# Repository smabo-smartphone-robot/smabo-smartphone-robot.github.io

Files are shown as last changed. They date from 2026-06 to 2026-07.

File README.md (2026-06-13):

# smabo-smartphone-robot.github.io

smabo プロジェクトの公式サイト（GitHub Pages）。

公開URL: <https://smabo-smartphone-robot.github.io/>

ビルド不要の静的サイト（プレーンな HTML / CSS / JS、外部ライブラリ依存なし）です。

## ファイル構成

```
.
├── index.html            # トップページ（特徴・システム構成・できること・リポジトリ）
├── components.html       # コンポーネント詳細（app / esp32 / brain）
├── roadmap.html          # ロードマップ
├── css/
│   ├── style.css         # サイト共通スタイル
│   ├── roadmap.css       # ロードマップ用
│   └── docs.css          # ドキュメント本文用（Markdown→HTML 表示）
├── js/
│   ├── main.js           # ナビ開閉・フッター年号
│   ├── roadmap.js        # ロードマップ用
│   └── docs.js           # ドキュメント用（Mermaid 描画・TOCスクロール追従）
├── assets/
│   ├── favicon.svg       # ファビコン
│   └── robot.svg         # ヒーローのロボットイラスト
├── docs/                 # ドキュメント（Markdown 正本 ＋ 生成 HTML を併置）
│   ├── index.md / index.html       # ドキュメントのトップ
│   ├── architecture/
│   │   └── design.md / design.html # 設計書（ESP32 ファームウェア設計）
│   ├── guides/                     # 製作ガイド（*.html）
│   └── images/                     # 図・スクショ
└── .nojekyll             # Jekyll 処理を無効化
```

## ドキュメント（Markdown ↔ HTML）

`docs/` 配下は **Markdown 版（正本）と HTML 版（公開用）を同じ場所・同じ名前で併置**します
（例: `architecture/design.md` ↔ `architecture/design.html`）。

- **Markdown** が編集の正本。記事を書く／直すときは `.md` を編集します。
- **HTML** は `.md` を元に生成します（サイト共通の `css/style.css` ＋ `css/docs.css` を適用、
  本文は `<article class="doc-content">` に流し込み、見出しからサイドバー目次を生成）。
- ` ```mermaid ` ブロックは `<pre class="mermaid">` として出力し、`js/docs.js` が
  Mermaid を CDN から読み込んで描画します（図を含むページのみ読み込み）。
- 変換はビルド工程を持たず、`.md` の内容を元に都度 HTML を作成します。`.md` を更新したら
  対応する `.html` を作り直してください。

## ローカルでの確認

```bash
# リポジトリ直下で簡易サーバを起動
python3 -m http.server 8000
# ブラウザで http://localhost:8000 を開く
```

## 公開（デプロイ）

`main` ブランチへ push すると GitHub Pages が自動で公開します
（Settings → Pages で Source を `main` / `/ (root)` に設定）。

## 編集メモ

- ヘッダーとフッターは各 HTML に直接記述しています（テンプレートエンジンなし）。
  ナビ項目を変更する場合は `index.html` と `components.html` の両方を更新してください。
- コンテンツは各リポジトリの README をもとにしています。仕様を変えたら本サイトも追従させてください。

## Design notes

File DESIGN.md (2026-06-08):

# ESP32 Robot Firmware — 設計ドキュメント

- **対象ファームウェア**: MicroPython (ESP32)
- **通信プロトコル**: rosbridge v2.0 互換 WebSocket JSON
- **更新日**: 2026-06-03

---

## 目次

1. [モジュール構成](#1-モジュール構成)
2. [クラス図](#2-クラス図)
3. [非同期タスク構成](#3-非同期タスク構成)
4. [シーケンス図](#4-シーケンス図)
   - 4-1. 起動
   - 4-2. WebSocket 接続確立
   - 4-3. 走行制御 (cmd_vel)
   - 4-4. サーボ手動制御（単一点）
   - 4-5. サーボ軌道制御（複数点・MoveIt2）
   - 4-6. ナビゲーション連携（Nav2）
   - 4-7. ランダム動作
   - 4-8. ソフト設定変更
   - 4-9. ハード設定変更（ピン変更・再起動）
   - 4-10. モード切り替え
   - 4-11. /joint_states 送信ループ
   - 4-12. オドメトリ送信ループ
   - 4-13. 設定の読み出し
5. [WebSocket メッセージ仕様](#5-websocket-メッセージ仕様)
6. [設定項目一覧](#6-設定項目一覧)
7. [設定変更の反映ルール](#7-設定変更の反映ルール)
8. [ハードウェア構成メモ](#8-ハードウェア構成メモ)

---

## 1. モジュール構成

```
esp32_robot/
├── main.py              # 起動エントリ・asyncio イベントループ
├── config.py            # 永続設定（RAM + config.json、デバウンス保存）
├── wifi_manager.py      # WiFi 接続・自動再接続
├── ws_server.py         # RFC 6455 WebSocket サーバ（外部ライブラリ不要）
├── robot.py             # オーケストレータ（rosbridge プロトコル・モード管理）
├── pca9685.py           # PCA9685 PWM ドライバ（サーボ用 I2C）
├── servo_controller.py  # JointGroup（全サーボ共通）
├── random_motion.py     # グループ単位のランダム動作（タイミンググループ管理）
├── dc_motors.py         # TB6612 差動駆動（cmd_vel 受信・デッドマン停止）
├── encoder.py           # GPIO 割り込みによるエンコーダカウント
└── odometry.py          # 差動駆動オドメトリ → nav_msgs/Odometry
```

---

## 2. クラス図

```mermaid
classDiagram
    direction TB

    class Config {
        +data : dict
        +get(path, default) any
        +set(path, value, persist)
        +update(partial, persist)
        +save_now()
        +mark_dirty(debounce_ms)
        +autosave_task() async
    }

    class WSServer {
        +port : int
        +clients : set
        +on_message : callable
        +start() async
        +broadcast(text)
        -_handshake(reader, writer) async
        -_read_loop(reader, writer) async
    }

    class Robot {
        +cfg : Config
        +pca : PCA9685
        +ws  : WSServer
        +servo_group   : JointGroup
        +random_motion : RandomMotion
        +drive    : DiffDrive
        +encoders : tuple
        +odom     : Odometry
        +start()
        +on_message(client, text)
        +apply_modes(modes)
        +publish(topic, msg)
        -_on_set_config(config_dict)
        -_reload_subsystems(changed_keys)
        -_joint_states_task() async
        -_reboot_after(ms, reasons) async
    }

    class PCA9685 {
        +i2c  : I2C
        +addr : int
        +set_freq(freq)
        +set_us(channel, us)
        +off(channel)
    }

    class JointGroup {
        +pca         : PCA9685
        +joints      : dict
        -_traj_queue : list
        +set_angle_deg(name, angle)
        +load_trajectory(names, points)
        +get_state() dict
        +run(dt) async
    }

    class RandomMotion {
        +group : JointGroup
        +cfg   : Config
        +run_group(group_name) async
        -_behavior() str
        -_group_cfg(name) dict
    }

    class DiffDrive {
        +cfg   : Config
        +left  : _Motor
        +right : _Motor
        +stby  : Pin
        +set_cmd_vel(linear_x, angular_z)
        +stop()
        +watchdog_task() async
    }

    class _Motor {
        +pwm  : PWM
        +in1  : Pin
        +in2  : Pin
        +drive(value)
        +stop()
    }

    class QuadEncoder {
        -_count : int
        +read() int
        +read_and_reset() int
    }

    class Odometry {
        +x     : float
        +y     : float
        +theta : float
        +vx    : float
        +wz    : float
        +update()
        +odom_msg() dict
        +run(publish) async
    }

    Robot --> Config         : 参照
    Robot --> WSServer       : 参照
    Robot --> PCA9685        : 参照
    Robot "1" *-- "0..1" JointGroup   : servo_group
    Robot "1" *-- "0..1" RandomMotion
    Robot "1" *-- "0..1" DiffDrive
    Robot "1" *-- "0..1" Odometry
    JointGroup   --> PCA9685    : PWM 出力
    RandomMotion --> JointGroup : 角度指令
    RandomMotion --> Config     : 参照（毎ループ読み直し）
    DiffDrive "1" *-- "2" _Motor : left / right
    Odometry --> QuadEncoder    : カウント読み取り
    Odometry --> Config         : 参照
    DiffDrive --> Config        : 参照
```

> **共通化ポイント**: 首・ハンド・アームを含む全サーボを `servo_group`（`JointGroup` の単一インスタンス）で管理します。
> ランダム動作のグループ分けは `RandomMotion` が担い、`JointGroup` 自体はグループを意識しません。

---

## 3. 非同期タスク構成

起動後に asyncio 上で動作するタスクの一覧です。
`Robot._tasks` で名前管理され、モード変更時に個別にキャンセル・再生成されます。

| タスク名 | コルーチン | 役割 | 起動条件 |
|---|---|---|---|
| `servo_follower` | `JointGroup.run()` | サーボ角度の速度制限追従・軌道キュー処理 | `modes.servos = true` |
| `random_<name>` | `RandomMotion.run_group(name)` | グループ単位のランダムタイマー（グループ数分起動） | `modes.servos = true` |
| `joint_states` | `Robot._joint_states_task()` | `/joint_states` 送信（MoveIt2連携用） | `modes.servos = true` |
| `drive_wd` | `DiffDrive.watchdog_task()` | cmd_vel デッドマン監視 | `dc_drive` or `encoder_drive` |
| `odom` | `Odometry.run()` | オドメトリ計算 + `/odom` 送信 | `modes.encoder_drive = true` |
| `autosave` | `Config.autosave_task()` | 設定デバウンス保存 | 常時 |
| `wifi_ka` | `wifi_manager.keepalive_task()` | WiFi 再接続監視 | 常時 |

> `random_<name>` のタスク名はグループ名から自動生成されます（例: `random_neck`, `random_hands`）。
> グループ数を変更すると `servos` モードが再起動され、新しいグループ数に合わせてタスクが再生成されます。

---

## 4. シーケンス図

### 4-1. 起動シーケンス

```mermaid
sequenceDiagram
    participant main
    participant Config
    participant WiFi as wifi_manager
    participant I2C/PCA as PCA9685
    participant WSServer
    participant Robot

    main->>Config: Config()
    Config->>Config: _load() — config.json を読み DEFAULTS とマージ
    main->>WiFi: connect(cfg)
    WiFi-->>main: WLAN オブジェクト

    main->>I2C/PCA: I2C() + PCA9685()
    main->>WSServer: WSServer(port, on_message)
    main->>Robot: Robot(cfg, pca, i2c, ws)
    main->>WSServer: ws.start()  ← TCP ソケットをオープン

    main->>Robot: robot.start()
    Robot->>Robot: apply_modes(cfg.modes)
    Robot->>Robot: enable_servos / enable_drive

    main->>main: asyncio tasks: autosave, wifi_keepalive
    Note over main: イベントループ開始 (sleep forever)
```

---

### 4-2. WebSocket 接続確立

```mermaid
sequenceDiagram
    participant Client as Web クライアント
    participant WSServer

    Client->>WSServer: TCP connect → HTTP GET (Upgrade: websocket)
    WSServer->>WSServer: SHA-1(key + GUID) → Sec-WebSocket-Accept
    WSServer-->>Client: HTTP 101 Switching Protocols
    Note over Client,WSServer: 以降 RFC 6455 フレームで双方向通信
    WSServer->>WSServer: clients.add(writer)
```

---

### 4-3. 走行制御 (cmd_vel)

```mermaid
sequenceDiagram
    participant Client
    participant WSServer
    participant Robot
    participant DiffDrive

    Client->>WSServer: {"op":"publish","topic":"/cmd_vel",\n"msg":{"linear":{"x":0.2},"angular":{"z":0.3}}}
    WSServer->>Robot: on_message(client, text)
    Robot->>Robot: _on_publish("/cmd_vel", msg)
    Robot->>DiffDrive: set_cmd_vel(0.2, 0.3)
    DiffDrive->>DiffDrive: 差動運動学 → v_l / v_r 正規化
    DiffDrive->>DiffDrive: left.drive(v_l),  right.drive(v_r)
    Note over DiffDrive: _last_cmd_ms を更新

    loop 100 ms ごと (watchdog_task)
        DiffDrive->>DiffDrive: ticks_diff > cmd_timeout?
        alt タイムアウト
            DiffDrive->>DiffDrive: stop()
        end
    end
```

---

### 4-4. サーボ手動制御 — 単一点 (JointTrajectory 1 点)

```mermaid
sequenceDiagram
    participant Client
    participant WSServer
    participant Robot
    participant JointGroup as servo_group

    Client->>WSServer: {"op":"publish","topic":"/servo/command",\n"msg":{"joint_names":["head_pan","head_tilt"],\n"points":[{"positions":[0.5,-0.2],"time_from_start":{"sec":0}}]}}
    WSServer->>Robot: on_message()
    Robot->>Robot: _on_publish("/servo/command", msg)
    Robot->>JointGroup: load_trajectory(names, points)
    JointGroup->>JointGroup: deadline = ticks_ms() + 0ms
    JointGroup->>JointGroup: _traj_queue = [(deadline, {head_pan:28.6°, head_tilt:-11.5°})]

    loop 20 ms ごと (servo_follower タスク)
        JointGroup->>JointGroup: deadline 到達 → _target 更新
        JointGroup->>JointGroup: max_speed 制限で _current を _target に近づける
        JointGroup->>PCA9685: set_us(channel, us)
    end
```

---

### 4-5. サーボ軌道制御 — 複数点 (MoveIt2 / time-parameterised)

```mermaid
sequenceDiagram
    participant SBC as SBC (MoveIt2)
    participant WSServer
    participant Robot
    participant JointGroup as servo_group

    SBC->>WSServer: {"op":"publish","topic":"/servo/command",\n"msg":{"joint_names":["arm_joint_1","arm_joint_2"],\n"points":[\n  {"positions":[0.0,0.0],"time_from_start":{"sec":0}},\n  {"positions":[0.5,0.3],"time_from_start":{"sec":1}},\n  {"positions":[1.0,0.6],"time_from_start":{"sec":2}}\n]}}
    WSServer->>Robot: on_message()
    Robot->>Robot: _on_publish("/servo/command", msg)
    Note over Robot: points が複数 → load_trajectory（時系列）
    Robot->>JointGroup: load_trajectory(names, points)
    JointGroup->>JointGroup: start_ms = ticks_ms()
    JointGroup->>JointGroup: _traj_queue = [(0ms,…),(1000ms,…),(2000ms,…)]

    loop 20 ms ごと (servo_follower タスク)
        JointGroup->>JointGroup: ticks_diff(now, deadline) >= 0 ?
        alt 次のポイントの時刻に到達
            JointGroup->>JointGroup: _target を該当ポイントの角度に更新
        end
        JointGroup->>JointGroup: max_speed 制限で _current を _target に追従
        JointGroup->>PCA9685: set_us(channel, us)
    end
```

> `time_from_start` は `load_trajectory()` 呼び出し時刻からの相対時間です。
> 各ポイントへの移動は `max_speed` (deg/s) の上限内でなめらかに追従します。

---

### 4-6. ナビゲーション連携（Nav2 + cmd_vel / odom）

```mermaid
sequenceDiagram
    participant PC
    participant SBC as SBC (ROS2 Nav2 + rosbridge)
    participant ESP32

    PC->>SBC: 目標位置 (geometry_msgs/PoseStamped)
    Note over SBC: Nav2 がパス計画・速度計算

    loop Nav2 制御ループ
        ESP32->>SBC: {"op":"publish","topic":"/odom","msg":{nav_msgs/Odometry}}
        Note over SBC: /odom を受信して自己位置を更新
        SBC->>ESP32: {"op":"publish","topic":"/cmd_vel","msg":{geometry_msgs/Twist}}
        Note over ESP32: DiffDrive.set_cmd_vel() → モータ制御
    end

    Note over SBC,ESP32: covariance が適切に設定されているため\nNav2 がオドメトリの信頼度を正しく評価できる
```

---

### 4-7. ランダム動作（グループ独立タイマー）

```mermaid
sequenceDiagram
    participant Client
    participant WSServer
    participant Robot
    participant RM as RandomMotion
    participant JG as servo_group (JointGroup)

    Client->>WSServer: {"op":"set_config","config":{"servos":{"behavior":"random"}}}
    WSServer->>Robot: on_message()
    Note over Robot: behavior は次のループで即時反映（再起動不要）

    par neck グループ (independent timer)
        loop random interval [1.0, 3.0] s
            RM->>RM: cfg から neck グループ設定を読む
            RM->>JG: set_angle_deg("head_pan",  random angle)
            RM->>JG: set_angle_deg("head_tilt", random angle)
            RM->>RM: sleep( random(1.0, 3.0) )
        end
    and hands グループ (independent timer)
        loop random interval [2.0, 5.0] s
            RM->>RM: cfg から hands グループ設定を読む
            RM->>JG: set_angle_deg("left_hand",  random angle)
            RM->>JG: set_angle_deg("right_hand", random angle)
            RM->>RM: sleep( random(2.0, 5.0) )
        end
    end
```

> グループ内のサーボは**同じ瞬間**に動き出しますが、目標角度はそれぞれ独立したランダム値です。
> グループ間のタイマーは完全に独立しており、自然にずれていきます。

---

### 4-8. 設定変更（ソフト設定 — サブシステム再起動のみ）

```mermaid
sequenceDiagram
    participant Client as Web 設定画面
    participant WSServer
    participant Robot
    participant Config

    Client->>WSServer: {"op":"set_config","config":{"servos":{"joints":{"head_pan":{"max_angle":80}}}}}
    WSServer->>Robot: on_message()
    Robot->>Robot: _on_set_config(config_dict)
    Robot->>Robot: _reboot_reasons() → [] (ピン変更なし)
    Robot->>Config: update({"servos":...})  ← deep-merge + mark_dirty
    Robot->>Robot: _reload_subsystems(["servos"])
    Robot->>Robot: _teardown_servos()  ← タスクキャンセル・インスタンス解放
    Robot->>Robot: enable_servos(True) ← 新設定で JointGroup + RandomMotion 再生成

    Note over Config: 2 秒後に autosave_task が config.json へ書き込み
```

---

### 4-9. 設定変更（ハード設定 — ピン変更 → 強制再起動）

```mermaid
sequenceDiagram
    participant Client as Web 設定画面
    participant WSServer
    participant Robot
    participant Config
    participant MCU as machine.reset()

    Client->>WSServer: {"op":"set_config","config":{"dc":{"pins":{"pwma":33}}}}
    WSServer->>Robot: on_message()
    Robot->>Robot: _on_set_config(config_dict)
    Robot->>Robot: _reboot_reasons() → ["dc.pins"]
    Robot->>Config: update({"dc":...})
    Robot->>Config: save_now()  ← 即時フラッシュ（再起動前に必ず保存）
    Robot->>Robot: asyncio.create_task(_reboot_after(500ms, reasons))
    Robot-->>Client: {"op":"notice","message":"Rebooting to apply: dc.pins"}
    Note over Client: UI に「再起動中...」を表示し再接続を試みる
    Robot->>MCU: (500 ms 後) machine.reset()
    MCU->>MCU: 新しいピン設定で起動
```

---

### 4-10. モード切り替え

```mermaid
sequenceDiagram
    participant Client
    participant WSServer
    participant Robot

    Client->>WSServer: {"op":"set_mode","modes":{"encoder_drive":true,"dc_drive":false}}
    WSServer->>Robot: on_message()
    Robot->>Robot: apply_modes(merged_modes)
    Note over Robot: encoder_drive と dc_drive の排他チェック
    Robot->>Robot: enable_servos(true)  ← モード変更なしなら再起動しない
    Robot->>Robot: disable_drive()  ← 既存タスクをキャンセル
    Robot->>Robot: enable_drive(with_encoder=true)
    Robot->>Config: update({"modes": ...})  ← 永続化
```

---

### 4-11. /joint_states 送信ループ

```mermaid
sequenceDiagram
    participant JointGroup as servo_group
    participant Robot
    participant Client as SBC / クライアント

    loop 1/joint_states_rate 秒ごと (デフォルト 20 Hz)
        Robot->>JointGroup: get_state()
        JointGroup-->>Robot: {"head_pan": 0.5, "head_tilt": -0.2, ...}
        Robot->>Client: {"op":"publish","topic":"/joint_states",\n"msg":{"name":[...],"position":[...],...}}
    end
```

> `servos.joint_states_rate = 0` で無効化できます。`modes.servos = false` のときは送信しません。

---

### 4-12. オドメトリ送信ループ

```mermaid
sequenceDiagram
    participant QuadEncoder
    participant Odometry
    participant Robot
    participant Client

    loop 1/publish_rate 秒ごと (デフォルト 20 Hz)
        Odometry->>QuadEncoder: enc_left.read_and_reset()
        Odometry->>QuadEncoder: enc_right.read_and_reset()
        Odometry->>Odometry: update() — 差動積分 → (x, y, θ)
        Odometry->>Robot: publish("/odom", odom_msg())
        Robot->>Client: {"op":"publish","topic":"/odom","msg":{...}}
    end
```

---

### 4-13. 設定の読み出し

```mermaid
sequenceDiagram
    participant Client as Web 設定画面
    participant WSServer
    participant Robot
    participant Config

    Client->>WSServer: {"op":"get_config"}
    WSServer->>Robot: on_message()
    Robot->>Config: cfg.data (全設定 dict)
    Robot-->>Client: {"op":"set_config","config":{...全設定...}}
```

---

## 5. WebSocket メッセージ仕様

### 接続情報

| 項目 | 値 |
|---|---|
| プロトコル | RFC 6455 WebSocket (テキストフレーム) |
| エンドポイント | `ws://<ESP32-IP>:9090` |
| デフォルトポート | `9090`（`config.ws.port` で変更可） |
| フォーマット | UTF-8 JSON、1 メッセージ = 1 フレーム |
| 認証 | なし（信頼済み LAN 内利用前提） |

---

### 5-1. クライアント → ESP32（受信）

#### `publish` — ロボット操作

| フィールド | 型 | 説明 |
|---|---|---|
| `op` | string | `"publish"` 固定 |
| `topic` | string | ROS トピック名 |
| `msg` | object | トピック型に対応した JSON |

---

**走行制御** `geometry_msgs/Twist`

```json
{
  "op": "publish",
  "topic": "/cmd_vel",
  "msg": {
    "linear":  {"x": 0.2,  "y": 0.0, "z": 0.0},
    "angular": {"x": 0.0,  "y": 0.0, "z": 0.3}
  }
}
```

| フィールド | 単位 | 範囲 |
|---|---|---|
| `linear.x` | m/s | `[-max_linear, +max_linear]` |
| `angular.z` | rad/s | `[-max_angular, +max_angular]` |

> `cmd_timeout` 秒以内にメッセージが届かない場合、モータは自動停止します。

---

**サーボ手動制御** `trajectory_msgs/JointTrajectory`

```json
{
  "op": "publish",
  "topic": "/servo/command",
  "msg": {
    "joint_names": ["head_pan", "head_tilt"],
    "points": [
      {
        "positions": [0.5, -0.2],
        "velocities": [],
        "time_from_start": {"sec": 1, "nanosec": 0}
      }
    ]
  }
}
```

| トピック | ルーティング先 |
|---|---|
| `/servo/command` | `servo_group` |

> - `joint_names` で対象サーボを指定。`servos.joints` に登録されていない名前は無視されます
> - `positions` の単位は **ラジアン**（ROS 標準）
> - 1点・複数点どちらも `load_trajectory()` で統一処理されます
> - 各点は `time_from_start` を絶対時刻に変換してキューに積み、`run()` ループで到達時刻になったら `_target` を更新します
> - 1点で `time_from_start=0` の場合は次の `run()` tick（≤20ms）で即時適用されます
> - `max_speed` 制限でなめらかに追従します（`0` = 即時移動）
> - `behavior` が `"random"` の場合でも手動コマンドは受け付けます（次のランダム発火で上書きされます）
> - `max_speed` (deg/s) による速度制限追従で移動します（`0` = 即時）

---

#### `set_mode` — モード切り替え

```json
{
  "op": "set_mode",
  "modes": {
    "servos":        true,
    "dc_drive":      false,
    "encoder_drive": true
  }
}
```

> `modes` は部分指定可。未指定のモードは現在値を維持します。
> `dc_drive` と `encoder_drive` は同時 `true` にできません（`encoder_drive` が優先）。

---

#### `set_config` — 設定変更

```json
{
  "op": "set_config",
  "config": {
    "servos": {
      "behavior": "random",
      "random_groups": [
        {"name": "neck",  "joints": ["head_pan", "head_tilt"], "interval": [1.0, 3.0]},
        {"name": "hands", "joints": ["left_hand", "right_hand"], "interval": [2.0, 5.0]}
      ]
    }
  }
}
```

> - 送信した部分のみ deep-merge されます（省略したキーは変更なし）
> - `servos.behavior` / `random_groups[*].interval` は次のループで即時反映（再起動不要）
> - `servos.joints` や `random_groups` のグループ追加・削除は `servos` モードが自動再起動されます
> - ピン・バス系変更時は自動的に `machine.reset()` が実行されます（後述）

---

#### `get_config` — 設定読み出し

```json
{"op": "get_config"}
```

→ ESP32 から `set_config` 形式で全設定が返ります。

---

#### `subscribe` / `advertise` / `unsubscribe`

rosbridge_suite との互換性のために受け付けます（内部動作への影響なし）。
`/odom` は `subscribe` なしでも全接続クライアントに broadcast されます。

---

### 5-2. ESP32 → クライアント（送信）

#### `publish` — 関節状態 `sensor_msgs/JointState`

```json
{
  "op": "publish",
  "topic": "/joint_states",
  "msg": {
    "header": {"stamp": {"sec": 1234, "nanosec": 0}, "frame_id": ""},
    "name":     ["head_pan", "head_tilt", "left_hand", "right_hand",
                 "arm_joint_1", "arm_joint_2", "arm_joint_3", "arm_joint_4"],
    "position": [0.5, -0.2, 0.0, 0.0, 0.0, 0.0, 0.0, 0.0],
    "velocity": [0.0, 0.0, 0.0, 0.0, 0.0, 0.0, 0.0, 0.0],
    "effort":   [0.0, 0.0, 0.0, 0.0, 0.0, 0.0, 0.0, 0.0]
  }
}
```

> `position` の単位は **ラジアン**（ROS 標準）。デフォルト **20 Hz** で送信。
> `servos.joint_states_rate` で変更可（`0` で無効）。`modes.servos = true` のときのみ送信。

---

#### `publish` — オドメトリ `nav_msgs/Odometry`

```json
{
  "op": "publish",
  "topic": "/odom",
  "msg": {
    "header": {
      "stamp": {"sec": 1234, "nanosec": 500000000},
      "frame_id": "odom"
    },
    "child_frame_id": "base_link",
    "pose": {
      "pose": {
        "position":    {"x": 0.12, "y": 0.05, "z": 0.0},
        "orientation": {"x": 0.0,  "y": 0.0,  "z": 0.087, "w": 0.996}
      },
      "covariance": [
        0.001, 0, 0, 0, 0, 0,
        0, 0.001, 0, 0, 0, 0,
        0, 0, 1e6, 0, 0, 0,
        0, 0, 0, 1e6, 0, 0,
        0, 0, 0, 0, 1e6, 0,
        0, 0, 0, 0, 0, 0.001
      ]
    },
    "twist": {
      "twist": {
        "linear":  {"x": 0.18, "y": 0.0, "z": 0.0},
        "angular": {"x": 0.0,  "y": 0.0, "z": 0.05}
      },
      "covariance": [
        0.001, 0, 0, 0, 0, 0,
        0, 1e6, 0, 0, 0, 0,
        0, 0, 1e6, 0, 0, 0,
        0, 0, 0, 1e6, 0, 0,
        0, 0, 0, 0, 1e6, 0,
        0, 0, 0, 0, 0, 0.001
      ]
    }
  }
}
```

> デフォルト **20 Hz** で送信（`encoder.publish_rate` で変更可・即時反映）。
> `encoder_drive` モードが無効のときは送信しません。
> covariance は `encoder.covariance.*` の5つの分散値から構築される 6×6 対角行列です。
> 計測不能な DoF（z, roll, pitch / vy, vz, wx, wy）は `1e6` で埋めてあり、Nav2 が正しく信頼度を評価できます。

---

#### `set_config` — get_config レスポンス

```json
{"op": "set_config", "config": { "...全設定..." }}
```

---

#### `notice` — 再起動通知

```json
{
  "op": "notice",
  "message": "Rebooting to apply pin/hw changes: dc.pins"
}
```

> このメッセージ受信後 約 500 ms で ESP32 が再起動します。
> Web 側は再接続ループを開始してください（再起動所要時間は約 3–5 秒）。

---

#### `error` — エラー通知

```json
{"op": "error", "message": "説明文"}
```

---

## 6. 設定項目一覧

### WiFi

| キー | 型 | デフォルト | 説明 |
|---|---|---|---|
| `wifi.ssid` | string | `"your-ssid"` | 接続先 SSID |
| `wifi.password` | string | `"your-password"` | パスワード |
| `wifi.hostname` | string | `"esp32-robot"` | mDNS ホスト名 |

> WiFi 設定は初回のみ `config.json` を直接書き込んで設定することを推奨します。
> WebSocket 経由での変更は再起動後に接続できなくなるリスクがあります。

### WebSocket

| キー | 型 | デフォルト | 説明 |
|---|---|---|---|
| `ws.port` | int | `9090` | リスンポート |

### I2C / PCA9685

| キー | 型 | デフォルト | 説明 |
|---|---|---|---|
| `i2c.sda` | int | `21` | SDA ピン番号 |
| `i2c.scl` | int | `22` | SCL ピン番号 |
| `i2c.freq` | int | `400000` | クロック周波数 (Hz) |
| `pca9685.address` | int | `0x40` | I2C アドレス |
| `pca9685.freq` | int | `50` | PWM 周波数 (Hz)。サーボ標準は 50 Hz |

### モード

| キー | 型 | デフォルト | 説明 |
|---|---|---|---|
| `modes.servos` | bool | `true` | サーボ制御（首・ハンド・アームを含む全サーボ） |
| `modes.dc_drive` | bool | `false` | DCモータ走行有効 |
| `modes.encoder_drive` | bool | `false` | エンコーダ付き走行有効 |

### サーボ共通スペック

各サーボ設定（`servos.joints.*`）が持つフィールドです。

| フィールド | 型 | 説明 |
|---|---|---|
| `channel` | int | PCA9685 チャンネル番号 (0–15) |
| `min_angle` | float | 最小角度 (deg) |
| `max_angle` | float | 最大角度 (deg) |
| `min_us` | int | 最小パルス幅 (µs)。デフォルト `500` |
| `max_us` | int | 最大パルス幅 (µs)。デフォルト `2500` |
| `init_angle` | float | 起動時の初期角度 (deg) |
| `max_speed` | float | 最大角速度 (deg/s)。`0` = 即時移動 |

### サーボ（`servos`）

首・ハンド・アームを含む全サーボを一括管理します。

| キー | 型 | デフォルト | 説明 |
|---|---|---|---|
| `servos.behavior` | string | `"manual"` | `"manual"` / `"random"` |
| `servos.joints` | dict | 下記参照 | 全サーボ定義。`joint名 → servo spec` |
| `servos.random_groups` | list | 下記参照 | ランダム動作のタイミンググループ定義 |
| `servos.joint_states_rate` | float | `20.0` | `/joint_states` 送信レート (Hz)。`0` で無効 |

**デフォルトの `servos.joints`**

| キー | デフォルト |
|---|---|
| `servos.joints.head_pan` | ch=0, ±90°, max_speed=120 |
| `servos.joints.head_tilt` | ch=1, ±45°, max_speed=120 |
| `servos.joints.left_hand` | ch=2, 0–90°, max_speed=0（即時） |
| `servos.joints.right_hand` | ch=3, 0–90°, max_speed=0（即時） |
| `servos.joints.arm_joint_1` | ch=4, ±90°, max_speed=90 |
| `servos.joints.arm_joint_2` | ch=5, ±90°, max_speed=90 |
| `servos.joints.arm_joint_3` | ch=6, ±90°, max_speed=90 |
| `servos.joints.arm_joint_4` | ch=7, ±90°, max_speed=90 |

> アームの軸数を変えるには `servos.joints` に `arm_joint_N` エントリを追加・削除します。`set_config` で変更後、`servos` モードが自動再起動されます。

**`servos.random_groups` — グループ定義**

| フィールド | 型 | 説明 |
|---|---|---|
| `name` | string | グループ識別名（タスク名 `random_<name>` に使用） |
| `joints` | list of string | このグループに属するサーボ名のリスト |
| `interval` | [float, float] | ランダム発火の待機時間範囲 (s)。`[最小, 最大]` |
| `saccade_prob` | float | 大きく素早い注視（サッカード）の確率 0–1（既定 0.18） |
| `drift` | float | ドリフト幅（可動域に対する割合・ガウス step、既定 0.07） |
| `center_pull` | float | 中立角への引き戻しの強さ 0–1（既定 0.12） |
| `drift_speed` | float | ドリフト速度（`max_speed` に対する割合、既定 0.4） |
| `long_pause_prob` | float | 時々の長い静止（settle）の確率 0–1（既定 0.22） |

> `saccade_prob` 以降は**生物的ランダム動作のチューニング**用（すべて任意・即時反映）。
> 省略時は既定値。サッカード時はフル `max_speed`、ドリフト時は `max_speed × drift_speed`。
> 動作モデル：通常は中立角へ引き戻しつつ微小ガウス step でゆらぎ（ドリフト）、
> 時々サッカードで大きく素早く動く。`max_speed`=0 のサーボはランダム時 120°/s で滑らかに動く。

**デフォルトのグループ構成**

```
neck  グループ: ["head_pan", "head_tilt"]  — 1.0〜3.0 秒ごとに同時発火
hands グループ: ["left_hand","right_hand"] — 2.0〜5.0 秒ごとに同時発火
```

> グループに属さないサーボは手動コマンド（`/servo/command`）でのみ動きます。

### DCモータ

| キー | 型 | デフォルト | 説明 |
|---|---|---|---|
| `dc.pins.stby` | int | `13` | TB6612 STBY ピン |
| `dc.pins.ain1` | int | `14` | 左モータ IN1 |
| `dc.pins.ain2` | int | `27` | 左モータ IN2 |
| `dc.pins.pwma` | int | `26` | 左モータ PWM |
| `dc.pins.bin1` | int | `25` | 右モータ IN1 |
| `dc.pins.bin2` | int | `33` | 右モータ IN2 |
| `dc.pins.pwmb` | int | `32` | 右モータ PWM |
| `dc.pwm_freq` | int | `1000` | PWM 周波数 (Hz) |
| `dc.max_linear` | float | `0.30` | 最大直進速度 (m/s) |
| `dc.max_angular` | float | `1.50` | 最大旋回速度 (rad/s) |
| `dc.wheel_radius` | float | `0.030` | 車輪半径 (m) |
| `dc.wheel_separation` | float | `0.150` | 車輪間距離 (m) |
| `dc.invert_left` | bool | `false` | 左モータ回転方向反転 |
| `dc.invert_right` | bool | `false` | 右モータ回転方向反転 |
| `dc.cmd_timeout` | float | `0.5` | デッドマンタイムアウト (s) |

### エンコーダ / オドメトリ

| キー | 型 | デフォルト | 説明 |
|---|---|---|---|
| `encoder.left.a` | int | `34` | 左エンコーダ A 相ピン |
| `encoder.left.b` | int | `35` | 左エンコーダ B 相ピン |
| `encoder.right.a` | int | `36` | 右エンコーダ A 相ピン |
| `encoder.right.b` | int | `39` | 右エンコーダ B 相ピン |
| `encoder.cpr` | int | `1440` | 車輪 1 回転あたりのカウント数 |
| `encoder.publish_rate` | float | `20.0` | /odom 送信レート (Hz) |
| `encoder.odom_frame` | string | `"odom"` | odom の frame_id |
| `encoder.base_frame` | string | `"base_link"` | child_frame_id |
| `encoder.covariance.pose_xx` | float | `0.001` | x位置分散 (m²) |
| `encoder.covariance.pose_yy` | float | `0.001` | y位置分散 (m²) |
| `encoder.covariance.pose_aa` | float | `0.001` | yaw分散 (rad²) |
| `encoder.covariance.twist_vv` | float | `0.001` | 線速度分散 ((m/s)²) |
| `encoder.covariance.twist_ww` | float | `0.001` | 角速度分散 ((rad/s)²) |

---

## 7. 設定変更の反映ルール

`set_config` で送られた内容は以下のルールで処理されます。

### 即時反映（再起動不要・サブシステム再起動なし）

ループ内で毎回 Config から読み直すため、変更は次の処理サイクルで自動反映されます。

| 設定 | 反映タイミング |
|---|---|
| `servos.behavior` | 各ランダムグループの次のループ開始時 |
| `servos.random_groups[*].interval` | 現在の sleep 終了後（次の待機から新しい範囲が適用） |
| `servos.random_groups[*].joints` | 次のランダム発火タイミングで反映 |
| `servos.joint_states_rate` | 次の /joint_states 送信後 |
| `dc.cmd_timeout` | 次の watchdog チェック (100 ms 以内) |
| `encoder.publish_rate` | 次の odom 送信後 |
| `encoder.covariance.*` | 次の odom 送信後（即時反映） |

### 即時反映（サブシステム再起動あり）

設定反映のためにサブシステムのタスクをキャンセルし、新設定でインスタンスを再生成します。
`servos` 再起動中はサーボが初期角度に戻ります（約 1 フレーム）。

| 変更キー | 再起動されるサブシステム | 具体的なトリガー例 |
|---|---|---|
| `servos.*` | `servo_follower`, `random_*` 全タスク, `joint_states` | サーボのチャンネル・角度範囲変更、グループ追加・削除、アーム軸の追加・削除 |
| `dc.*`（`pins` 以外） | `drive_wd`, `odom` | 速度上限・反転設定変更 |
| `encoder.*`（ピン以外） | `drive_wd`, `odom` | CPR 値変更 |

### 強制再起動（`machine.reset()`）

ピン割り当て・バスパラメータはペリフェラルの再初期化が必要なため、
設定を即時保存してから ESP32 をリセットします。

| 変更キー | 理由 |
|---|---|
| `i2c.*` | `machine.I2C` の再生成が必要 |
| `pca9685.*` | I2C バス上のデバイス再初期化 |
| `wifi.*` | `network.WLAN` の再接続（**下記注意参照**） |
| `dc.pins.*` | `machine.PWM` / `machine.Pin` の再生成 |
| `encoder.left.*` | `machine.Pin` + IRQ の再設定 |
| `encoder.right.*` | 同上 |

> **WiFi 設定変更の注意**: WebSocket は WiFi の上に乗っているため、SSID/Password を
> WebSocket 経由で変更すると再起動後に接続できなくなるリスクがあります。
> **WiFi 設定は初回のみ `config.json` を直接書き込んで設定し、以後は変更しない運用を推奨します。**
> 変更が必要な場合はシリアル(USB)経由で `config.json` を直接編集してください。

**再起動フロー:**
1. `config.json` に即時保存（`save_now()`）
2. `{"op":"notice","message":"Rebooting to apply: ..."}` を送信
3. 500 ms 後に `machine.reset()`
4. 起動後に新設定が自動的に読み込まれる

---

## 8. ハードウェア構成メモ

### PWM バスの分離

```
PCA9685 (I2C)  ←→  サーボ全軸（首・ハンド・アーム）  @ 50 Hz
ESP32 LEDC PWM ←→  DCモータドライバ（TB6612）        @ 1 kHz
```

> PCA9685 の PWM 周波数は 16ch 共通のため、サーボ(50 Hz)とモータ(1 kHz)を
> 同一デバイスに混在させると両立しません。

### エンコーダピンの注意

- GPIO **34–39** は入力専用・内部プルアップ無し → **外部プルアップ抵抗が必須**
- ソフトウェア IRQ カウントのため高速回転では取りこぼしが発生します
- 高精度が必要な場合は ESP32 PCNT バインディング入りカスタムファームウェアを推奨

### デフォルト PCA9685 チャンネル割り当て

| ch | `servos.joints` のキー名 | デフォルト用途 |
|---|---|---|
| 0 | `head_pan` | 首 パン |
| 1 | `head_tilt` | 首 チルト |
| 2 | `left_hand` | 左ハンド |
| 3 | `right_hand` | 右ハンド |
| 4 | `arm_joint_1` | アーム 第1軸 |
| 5 | `arm_joint_2` | アーム 第2軸 |
| 6 | `arm_joint_3` | アーム 第3軸 |
| 7 | `arm_joint_4` | アーム 第4軸 |

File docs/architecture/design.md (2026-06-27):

# smabo — システム設計ドキュメント

- **対象**: smabo（スマホロボット）システム全体（smabo-app / smabo-web / smabo-brain / smabo-esp32 / smabo-brain-ros）
- **通信プロトコル**: rosbridge v2.0 互換 WebSocket JSON。中継サーバ **smabo-brain** を中心としたハブ&スポーク構成
- **設定系**: config / mode は smabo-web ↔ smabo-esp32 の REST 直通（smabo-brain を経由しない）
- **更新日**: 2026-06-25

> 本ドキュメントは、smabo システム全体の構成（[システム全体構成](#システム全体構成) / [コンポーネント概要](#コンポーネント概要)）と、
> 各コンポーネントのうち最も実装詳細の多い **smabo-esp32（ファームウェア）の詳細**（§1〜§8）をまとめます。

---

## 目次

- [システム全体構成](#システム全体構成)
  - [コンポーネント構成](#コンポーネント構成)
  - [通信トポロジ](#通信トポロジ)
  - [通信モデル](#通信モデル)
  - [送信元 prefix 規約](#送信元-prefix-規約)
  - [主要トピックとデータフロー](#主要トピックとデータフロー)
  - [WebSocket エンドポイントとルーティング](#websocket-エンドポイントとルーティング)
  - [各クライアントの送受信トピック（WebSocket 全網羅）](#各クライアントの送受信トピックwebsocket-全網羅)
  - [WebSocket 通信シーケンス（app を含む全経路）](#websocket-通信シーケンスapp-を含む全経路)
  - [メッセージ定義（app / web）](#メッセージ定義app-web)
- [コンポーネント概要](#コンポーネント概要)
- [画像処理（物体検出と追従）](#画像処理物体検出と追従)
  - [データフロー](#データフロー)
  - [処理モード](#処理モード)
  - [コンポーネントと配置](#コンポーネントと配置)
  - [制御メッセージ（/vision/config）](#制御メッセージvisionconfig)
  - [起動時初期値とメッセージ型の選定](#起動時初期値とメッセージ型の選定)
  - [メッセージ定義（vision）](#メッセージ定義vision)
  - [policy（pixel→方向→各指令）](#policypixel方向各指令)
- **smabo-esp32（ファームウェア）詳細**
  1. [モジュール構成](#1-モジュール構成)
  2. [クラス図](#2-クラス図)
  3. [非同期タスク構成](#3-非同期タスク構成)
  4. [シーケンス図](#4-シーケンス図)
  5. [WebSocket メッセージ仕様](#5-websocket-メッセージ仕様)
  6. [設定項目一覧](#6-設定項目一覧)
  7. [設定変更の反映ルール](#7-設定変更の反映ルール)
  8. [ハードウェア構成メモ](#8-ハードウェア構成メモ)

---

## システム全体構成

smabo は、中継サーバ **smabo-brain** を中心に各コンポーネントが WebSocket クライアントとして
ぶら下がる**ハブ&スポーク構成**です。各コンポーネントは smabo-brain の宛先だけを知っていればよく、
相互の直接接続は持ちません（設定系の REST 直通を除く）。

### コンポーネント構成

| コンポーネント | 役割 | 実装 | smabo-brain への接続 |
|---|---|---|---|
| smabo-app | smabo の「顔（目）」とスマホセンサ（IMU / GPS / カメラ / ウェイクワード検出＋音声録音） | Flutter（スマートフォン） | WS `/` |
| smabo-web | 制御 UI・テレメトリ可視化・設定 | React / TypeScript（ブラウザ） | WS `/ui`（＋ ESP32 へ設定を REST 直） |
| smabo-brain | 中継ハブ＋マイコンでできない上位処理（オドメトリ積分等） | Python / aiohttp（PC / SBC） | **サーバ**（待受 `:9090`） |
| smabo-esp32 | アクチュエータ制御・センサ取得 | MicroPython（ESP32 系） | WS `/esp32` |
| smabo-brain-ros | ROS 2 連携（rosbridge_suite / Nav2 / MoveIt2） | ROS 2（SBC） | rosbridge（WS `:9090`） |

### 通信トポロジ

```mermaid
graph TB
    app["smabo-app（顔・センサ）"]
    web["smabo-web（制御UI）"]
    esp32["smabo-esp32（アクチュエータ／センサ）"]
    brain{{"smabo-brain　中継ハブ :9090"}}
    ros["smabo-brain-ros（Nav2 / MoveIt2）"]

    app <--> |"WS /（/app prefix）"| brain
    web <--> |"WS /ui（/web prefix）"| brain
    esp32 <--> |"WS /esp32 prefix"| brain
    web -.-> |"REST /config /mode（直通）"| esp32
    brain <--> |"rosbridge で ROS2 連携"| ros
```

### 通信モデル

| 項目 | 内容 |
|---|---|
| プロトコル | RFC 6455 WebSocket、UTF-8 JSON（rosbridge v2.0 互換）、1 メッセージ = 1 フレーム |
| 待受 | smabo-brain が `:9090` でサーバ。接続元ごとにパスを分ける（app=`/`、web=`/ui`、esp32=`/esp32`） |
| 設定系 | config / mode は smabo-web ↔ smabo-esp32 の **REST 直通**（smabo-brain を経由しない） |
| ROS 2 連携 | smabo-brain-ros 構成では rosbridge_server（`:9090`）が WS ↔ ROS 2 を相互変換 |
| 認証 | なし（信頼済み LAN 内利用前提） |

### 送信元 prefix 規約

各クライアントは publish するトピックに**送信元 prefix** を付けて送ります
（smabo-app → `/app`、smabo-web → `/web`、smabo-esp32 → `/esp32`）。
smabo-brain はこの prefix を**剥がしてから** canonical なトピック名で宛先へ再配信します
（例: esp32 が送る `/esp32/wheel_vel` → 積分後 `/odom`、web が送る `/web/cmd_vel` → `/cmd_vel`）。
受信側は常に prefix 無しの canonical 名で受け取ります。
`set_config` / `get_config` / `call_service` など publish 以外の op には prefix は付きません。

### 主要トピックとデータフロー

| トピック | 型 | 送信元 → 宛先 | 内容 |
|---|---|---|---|
| `/cmd_vel` | geometry_msgs/Twist | smabo-web / Nav2 → smabo-esp32 | 走行速度指令 |
| `/wheel_vel` → `/odom` | （esp32 独自）→ nav_msgs/Odometry | esp32 → brain で積分 → web / Nav2 | ホイール速度 → オドメトリ |
| `/servo/command` | trajectory_msgs/JointTrajectory | smabo-web / MoveIt2 → smabo-esp32 | サーボ軌道指令 |
| `/joint_states` | sensor_msgs/JointState | smabo-esp32 → web / MoveIt2 | 関節角度 |
| `/scan` | sensor_msgs/LaserScan | smabo-esp32（LD06）→ brain → Nav2 | ライダ |
| `/imu/data`・`/gps/fix` | 各標準型 | smabo-app → smabo-web | スマホセンサ |
| カメラ映像（WebRTC, H.264/VP8） | — | smabo-app → smabo-brain（web へはプレビュー時のみ中継） | カメラ |
| `/look_at`・`/expression`・`/speech/say` | — | smabo-web → smabo-app | 顔（目）・発話の制御 |
| `/speech/audio` | audio_common_msgs/AudioData（base64 WAV） | smabo-app → smabo-brain | wake 後に録音した発話音声（brain が STT） |
| `/speech/recognized` | std_msgs/String | smabo-brain → smabo-web | 音声認識結果（brain が STT した文字列） |

### WebSocket エンドポイントとルーティング

smabo-brain は接続元ごとにパスを分けてサーバ（`:9090`）として待ち受け、受け取った publish を
**送信元 prefix を剥がして** canonical 名で適切な宛先へ中継します。

| エンドポイント | 接続元 | smabo-brain の処理 |
|---|---|---|
| `/` | smabo-app | app の publish（`/app` prefix）を剥がして **smabo-web（UI）へ中継**。ただし `/webrtc/*`（offer/ICE）と `/speech/audio` は **smabo-brain が消費**し（前者は WebRTC ピア、後者は STT）、web へは中継しない |
| `/ui` | smabo-web | publish（`/web` prefix）を剥がし、`/speech/say`・`/expression`・`/look_at` は **smabo-app へ**、`/vision/config`・`/webrtc/*` は **smabo-brain が消費**、それ以外は **smabo-esp32 へ**。publish 以外の op（`set_config` / `get_config` / `set_mode` 等）は smabo-esp32 へ |
| `/esp32` | smabo-esp32 | publish（`/esp32` prefix）を剥がし、`/wheel_vel` は積分して `/odom` を **UI へ**、それ以外は **UI へ**。esp32 が push する `set_config` は brain のオドメトリ同期にのみ使用 |

> 「web → app」へ流れるのは `/speech/say`・`/expression`・`/look_at` の3つだけです
> （`brain.topics.APP_TOPICS`）。`/vision/config` と `/webrtc/*`（プレビュー/シグナリング）は
> smabo-brain が消費し、残りの smabo-web の publish が smabo-esp32 宛になります。

### 各クライアントの送受信トピック（WebSocket 全網羅）

**smabo-app**（パス `/`、publish には `/app` prefix を付与）

| 方向 | トピック | 型 |
|---|---|---|
| 送信（app → brain → web） | `/imu/data` | sensor_msgs/Imu |
| 送信 | `/gps/fix` | sensor_msgs/NavSatFix |
| 送信（app → brain、STT 用） | `/speech/audio`（wake 後の録音音声、base64 WAV） | audio_common_msgs/AudioData |
| 送信（WebRTC、app → brain） | カメラ映像 + `/webrtc/offer`・`/webrtc/app_ice`（シグナリング） | — |
| 受信（WebRTC、brain → app） | `/webrtc/answer` | — |
| 受信（web → brain → app） | `/look_at` | geometry_msgs/PoseStamped |
| 受信 | `/expression` | std_msgs/Int32 |
| 受信 | `/speech/say` | std_msgs/String |

**smabo-web**（パス `/ui`、publish には `/web` prefix を付与）

| 方向 | トピック | 相手 |
|---|---|---|
| 送信 | `/cmd_vel`・`/servo/command`・`/ping`・（Nav2 用 `/initialpose`・`/goal_pose`） | → smabo-esp32 |
| 送信 | `/look_at`・`/expression`・`/speech/say` | → smabo-app |
| 送信（非 publish op） | `get_config`・`set_config`・`set_mode` | → smabo-esp32（※設定は通常 REST 直通を使用） |
| 送信（WebRTC プレビュー） | `/webrtc/preview`（ON/OFF）・`/webrtc/web_answer`・`/webrtc/web_ice` | → smabo-brain |
| 受信（app 由来） | `/imu/data`・`/gps/fix` | ← smabo-app |
| 受信（brain 由来） | `/speech/recognized`（brain が STT した文字列） | ← smabo-brain |
| 受信（WebRTC 中継・プレビュー時のみ） | カメラ映像 + `/webrtc/web_offer` | ← smabo-brain |
| 受信（esp32 由来） | `/odom`（`/wheel_vel` を積分）・`/joint_states`・`/scan`・`/pong`・`notice`・`error` | ← smabo-esp32 |

**smabo-esp32**（パス `/esp32`、publish には `/esp32` prefix を付与。メッセージ詳細は §5）

| 方向 | トピック | 型 |
|---|---|---|
| 送信 | `/wheel_vel`（→ brain で `/odom` に積分） | left / right / dt |
| 送信 | `/joint_states` | sensor_msgs/JointState |
| 送信 | `/scan`（LD06、`modes.lidar` 時） | sensor_msgs/LaserScan |
| 送信 | `/pong`（`/ping` のエコー）・`set_config`・`notice`・`error` | std_msgs/String 他 |
| 受信 | `/cmd_vel` | geometry_msgs/Twist |
| 受信 | `/servo/command` | trajectory_msgs/JointTrajectory |
| 受信 | `/ping` | std_msgs/String |

### WebSocket 通信シーケンス（app を含む全経路）

```mermaid
sequenceDiagram
    participant app as smabo-app
    participant brain as smabo-brain
    participant web as smabo-web
    participant esp32 as smabo-esp32

    Note over app,esp32: ① スマホセンサ（app → web）
    app->>brain: publish /app/imu/data・/app/gps/fix …
    brain->>web: /app を剥がし /imu/data・/gps/fix を配信
    Note over app,brain: カメラ映像は WebRTC（app → brain、シグナリングは /webrtc/*）

    Note over app,esp32: ② 顔・発話の制御（web → app）
    web->>brain: publish /web/look_at（/expression・/speech/say）
    brain->>app: APP_TOPICS なので /look_at を app へ配信

    Note over app,esp32: ③ 走行・サーボ（web → esp32）
    web->>brain: publish /web/cmd_vel・/web/servo/command
    brain->>esp32: /web を剥がし /cmd_vel・/servo/command を配信

    Note over app,esp32: ④ ロボット状態（esp32 → web）
    esp32->>brain: publish /esp32/wheel_vel・/esp32/joint_states・/esp32/scan
    brain->>web: /wheel_vel を積分して /odom、他は canonical 名で配信
```

### メッセージ定義（app / web）

rosbridge v2.0 互換の JSON です（`{"op":"publish","topic":...,"msg": <下記>}` の `msg` 部分）。
すべての `header` は `{"stamp":{"sec":<int>,"nanosec":<int>}, "frame_id":<string>}` 形式です。
smabo-esp32 が扱う `/cmd_vel`・`/servo/command`・`/joint_states`・`/wheel_vel` の定義は §5 を参照してください。

**`/imu/data` — sensor_msgs/Imu**（smabo-app → smabo-web）

```json
{
  "header": {"stamp": {"sec": 0, "nanosec": 0}, "frame_id": "imu_link"},
  "orientation": {"x": 0.0, "y": 0.0, "z": 0.0, "w": 1.0},
  "orientation_covariance": [0,0,0, 0,0,0, 0,0,0],
  "angular_velocity": {"x": 0.0, "y": 0.0, "z": 0.0},
  "angular_velocity_covariance": [0,0,0, 0,0,0, 0,0,0],
  "linear_acceleration": {"x": 0.0, "y": 0.0, "z": 9.81},
  "linear_acceleration_covariance": [0,0,0, 0,0,0, 0,0,0]
}
```

**`/gps/fix` — sensor_msgs/NavSatFix**（smabo-app → smabo-web）

```json
{
  "header": {"stamp": {"sec": 0, "nanosec": 0}, "frame_id": "gps"},
  "status": {"status": 0, "service": 1},
  "latitude": 35.681,
  "longitude": 139.767,
  "altitude": 40.0,
  "position_covariance": [c,0,0, 0,c,0, 0,0,c],
  "position_covariance_type": 1
}
```

> `position_covariance` の対角 `c` は水平精度の二乗（`horizontalAccuracy²`）。
> `status.status`=0（FIX）/ `service`=1（GPS）、`position_covariance_type`=1（APPROXIMATED）。

**カメラ映像 — WebRTC**（smabo-app → smabo-brain）

カメラ映像は WebRTC で smabo-app から smabo-brain へ送られます。映像メディア本体は
P2P（ローカル WiFi のホスト候補のみ、STUN/TURN なし）で流れ、`/camera/image/compressed`
のような WebSocket トピックは使用しません。シグナリング（SDP / ICE 交換）だけが brain の
WebSocket を経由します。

| トピック | 向き | 内容 |
|---|---|---|
| `/webrtc/offer` | app → brain | オファー SDP（`{"data": "<JSON: sdp/type>"}`） |
| `/webrtc/answer` | brain → app | アンサー SDP（brain の ICE 候補を SDP に同梱） |
| `/webrtc/app_ice` | app → brain | app の ICE 候補 |

> smabo-brain は受信した映像からフレームを取り出して画像処理（§「画像処理」参照）に通し、
> smabo-web がプレビューを ON にしている間だけ、同じ映像を `/webrtc/web_offer` で web へ中継します。

**`/look_at` — geometry_msgs/PoseStamped**（smabo-web → smabo-app、視線追従の目標）

```json
{
  "header": {"stamp": {"sec": 0, "nanosec": 0}, "frame_id": "base_link"},
  "pose": {
    "position":    {"x": 1.0, "y": -0.3, "z": 0.2},
    "orientation": {"x": 0.0, "y": 0.0, "z": 0.0, "w": 1.0}
  }
}
```

> `position` を方向ベクトルとして解釈します（REP-103: x=前 / y=左 / z=上）。
> smabo-app は `gazeX = -y/x`・`gazeY = -z/x` で画面上の視線方向へ変換します（`pose` 無しの bare `Pose` も受理）。

**`/expression` — std_msgs/Int32**（smabo-web → smabo-app、表情ID）

```json
{"data": 3}
```

**`/speech/say` — std_msgs/String**（smabo-web → smabo-app、読み上げテキスト）
**`/speech/recognized` — std_msgs/String**（smabo-brain → smabo-web、認識テキスト）

```json
{"data": "こんにちは"}
```

**`/speech/audio` — audio_common_msgs/AudioData**（smabo-app → smabo-brain、wake 後に録音した発話音声）

```json
{"data": "<base64 エンコードした 16kHz モノラル WAV>"}
```

> `data` は `uint8[]`（rosbridge では base64 文字列）。中身は自己記述的な WAV（ヘッダに
> フォーマット / サンプルレート / チャンネルを持つ）なので追加フィールドは不要です。

> **音声認識の流れ**：smabo-app は**ウェイクワード検出だけ**を担当します。ウェイクワードを
> 検出すると発話を録音し（16kHz モノラル、無音が一定時間続いたら停止）、WAV を base64 化して
> `/speech/audio`（`audio_common_msgs/AudioData`）で smabo-brain に送ります。smabo-brain は受信音声を STT エンジン
> （既定 vosk、`--stt-engine whisper` で faster-whisper も選択可）で文字起こしし、結果を
> `/speech/recognized` として配信します（smabo-web で確認できます）。
> ウェイクワード検出には Android の音声認識を用いるため、待ち受け中は `error_speech_timeout`
> が周期的に出ますが正常で、smabo-app 側がバックオフ付きで穏やかに待ち受けを再開します。

**`/odom` — nav_msgs/Odometry**（smabo-brain が `/wheel_vel` を積分して生成 → smabo-web / Nav2）

```json
{
  "header": {"stamp": {"sec": 0, "nanosec": 0}, "frame_id": "odom"},
  "child_frame_id": "base_link",
  "pose":  {"pose":  {"position": {"x": 0.0, "y": 0.0, "z": 0.0},
                      "orientation": {"x": 0.0, "y": 0.0, "z": 0.0, "w": 1.0}},
            "covariance": ["…6×6 行優先 36 要素…"]},
  "twist": {"twist": {"linear":  {"x": 0.0, "y": 0.0, "z": 0.0},
                      "angular": {"x": 0.0, "y": 0.0, "z": 0.0}},
            "covariance": ["…6×6 行優先 36 要素…"]}
}
```

> `covariance`（各 36 要素）は smabo-brain が `encoder.covariance.*` から付与します。

**`/scan` — sensor_msgs/LaserScan**（smabo-esp32 の LD06 → smabo-brain → Nav2）

```json
{
  "header": {"stamp": {"sec": 0, "nanosec": 0}, "frame_id": "laser"},
  "angle_min": 0.0,
  "angle_max": 6.2657,
  "angle_increment": 0.01745,
  "time_increment": 0.0,
  "scan_time": 0.1,
  "range_min": 0.05,
  "range_max": 12.0,
  "ranges": ["…距離(m) の配列。0.0 は無反射…"],
  "intensities": []
}
```

**`/ping` / `/pong` — std_msgs/String**（疎通確認。web → esp32 が `/ping`、esp32 → web が `/pong` でエコー）

```json
{"data": "<往復照合用トークン>"}
```

> **rosbridge モード（smabo-brain-ros）**では、上記の中継・prefix 剥がしを rosbridge_server ＋
> relay ノードが担います。各クライアントは publish の前に `advertise`、受信の前に `subscribe` が
> 必要です（詳細は smabo-brain-ros の README を参照）。

---

## コンポーネント概要

### smabo-app

smabo の「顔（目）」を表示し、スマートフォンの IMU / GPS / カメラをセンサとして提供します。
音声はウェイクワード検出と録音だけを担当し（STT は smabo-brain）、ウェイクワード後の録音音声を
`/speech/audio` で送ります。WS `/` で smabo-brain に接続し、`/app` prefix でセンサを publish、
`/look_at`・`/expression`・`/speech/say` を受けて目や発話を制御します。

### smabo-web

ブラウザ上の制御 UI（React / TypeScript）。Face / Sensors / Drive / Servo / Config / Log タブに加え、
ROS 2 連携時は Navigation / Motion Plan タブ（roslib + 3D ビューア）で Nav2 / MoveIt2 を操作します。
WS `/ui` で smabo-brain に接続（`/web` prefix）。config / mode は ESP32 へ **REST 直通**で設定します。

### smabo-brain

全コンポーネントが接続する中継ハブ（aiohttp）。送信元 prefix を剥がして canonical 名で再配信し、
マイコンではできない上位処理（**オドメトリ積分** `/wheel_vel` → `/odom`、カメラ映像の画像処理、
`/speech/audio` の**音声認識（STT）** → `/speech/recognized` など）を担います。STT エンジンは
既定 vosk、`--stt-engine whisper` で faster-whisper も選択できます（`brain.stt`、未導入なら無効）。
純ロジック（`brain.odometry`・`brain.topics`）は transport から分離されており、
smabo-brain-ros が import して再利用します。

### smabo-brain-ros

smabo-brain の ROS 2 ラッパー兼 ROS 2 ランタイム。rosbridge_suite（WS ↔ ROS 2）＋ Nav2（ナビゲーション）
＋ MoveIt2（動作計画）＋ odom_node ＋ 画像処理（`brain.vision` 再利用）＋ 音声認識
（`speech_recognizer_node`：`/speech/audio`→STT→`/speech/recognized`、`brain.stt` 再利用）を提供します。
外部（web / app / esp32）は rosbridge 経由で ROS グラフに接続し、smabo-brain の純ロジックを再利用します。

> **カメラ映像は rosbridge をバイパス**します。rosbridge は JSON over WebSocket のため、映像を
> `/camera/image/compressed`（base64 JSON）として通すとリアルタイム性が落ちます。そこで
> smabo-brain-ros は **WebRTC 終端ノード**（`webrtc_camera_node`、`brain.webrtc_hub` を再利用）を
> 持ち、smabo-app からの WebRTC 映像を終端してフレームを取り出し、**ネイティブ ROS の
> `sensor_msgs/Image`（`/camera/image_raw`）として DDS に publish** します。これを
> `image_processor_node` 等が購読するため、ROS グラフ内は高速なネイティブ転送になります。
> WebRTC のシグナリング（`/webrtc/*`、小さい JSON）は rosbridge 経由で問題ありません。

### smabo-esp32（概要）

ESP32 上の MicroPython ファームウェア。サーボ（PCA9685）・DC モータ（TB6612）・エンコーダ・
LD06 ライダを制御 / 取得します。WS `/esp32` で smabo-brain に接続。**詳細は §1 以降**を参照してください。

---

## 画像処理（物体検出と追従）

smabo-app のカメラ映像（**WebRTC**）を smabo-brain（および smabo-brain-ros）が受け取り、
`capture_fps`（`/vision/config`）の頻度でフレームを取り出して物体の**画像内位置**を算出し、
`vision_msgs/Detection2DArray` 互換で配信します。
その検出結果から、**目（`/look_at`）・首サーボ（`/servo/command`）・走行（`/cmd_vel`）**の
各 behavior が「対象を向く／追従する」動きを生成します。検出（知覚）と振る舞い（behavior）を
分離し、同じ検出結果を複数アクチュエータで再利用できる構成です。

> 純ロジック（検出・幾何変換・各 policy）は `brain.vision` に集約し、smabo-brain（WS）と
> smabo-brain-ros（ROS2）が import して再利用します（`brain.odometry` と同じ分離方針）。

### データフロー

```mermaid
sequenceDiagram
    participant app as smabo-app
    participant brain as smabo-brain / brain-ros
    participant web as smabo-web
    participant esp32 as smabo-esp32

    web->>brain: /vision/config（mode/color/speak/behaviors/capture_fps …）
    app->>brain: カメラ映像（WebRTC）
    Note over brain: フレームを取り出し brain.vision で検出（aruco/color/face/qr）
    brain->>web: /vision/detections（Detection2DArray）・/vision/markers（String）
    Note over brain: 最大面積の検出 → 方向に変換 → 各 policy
    brain->>app: /look_at（目を向ける）
    brain->>esp32: /servo/command（首を向ける）
    brain->>esp32: /cmd_vel（mobile_robot 追従）
    brain->>app: /speech/say（AR/QR 文字列の発話・任意）
    brain->>web: カメラ映像中継（WebRTC、プレビュー ON 時のみ）
```

### 処理モード

| モード | 内容 | 文字列配信 |
|---|---|---|
| `off` | 無効 | — |
| `aruco` | AR マーカー検出（位置＋ID）。辞書は `aruco_dict`（`"ALL"` で全辞書走査） | マーカー番号 → `/vision/markers` |
| `color` | 指定色の物体の中心（HSV しきい値）。色はカラーパレットの任意 RGB（`color_rgb`）または名前付きプリセット | — |
| `face` | 顔検出（OpenCV Haar） | — |
| `qr` | QR コード（位置＋内容） | 内容 → `/vision/markers` |

> `speak=true` のとき、`aruco` の番号 / `qr` の内容を `/speech/say` に流して smabo-app が発話します。
> 同じ文字列の連投は brain 側で抑制（変化時のみ送出）し、smabo-app 側にも
> 「同一文字列を連続受信したら無視する」設定を用意します。

### コンポーネントと配置

| 役割 | smabo-brain（WS） | smabo-brain-ros（ROS2） |
|---|---|---|
| 検出 | カメラ受信 → `brain.vision` → `/vision/detections`・`/vision/markers` を配信 | `image_processor_node`（CompressedImage → Detection2DArray ＋ String） |
| gaze policy | detections → `/look_at` | `gaze_policy_node` |
| neck policy | detections → `/servo/command` | `neck_policy_node` |
| drive policy | detections → `/cmd_vel`（mobile_robot 追従） | `drive_policy_node` |
| 制御 | `/vision/config` を intercept | `image_processor_node` が subscribe |

> CV は重いので brain では**別スレッド（executor）で実行**して中継ループを止めません。処理は**間引き**（例 10 fps）。

### 制御メッセージ（/vision/config）

smabo-web → smabo-brain（rosbridge モードでは relay 経由）。`std_msgs/String` の `data` に設定 JSON（文字列）を入れます。**部分指定**でよく、brain は現在値に **deep-merge**（`target_joints` / `behaviors` / `drive` はキー単位でマージ、スカラは置換）して保持します。更新後は brain が**正規化済みスナップショットを全 UI に再配信**し、新規接続 UI には接続直後に現在値を1通送って同期します。

```json
{
  "enabled": true,
  "mode": "color",
  "color": "red",
  "color_rgb": "#1e90ff",
  "color_hue_tol": 12,
  "color_s_min": 70,
  "color_v_min": 60,
  "min_area_frac": 0.0008,
  "aruco_dict": "DICT_4X4_50",
  "speak": false,
  "hfov_deg": 60.0,
  "target_marker_id": null,
  "target_joints": {"pan": "head_pan", "gain": 1.0},
  "behaviors": {"look_at": true, "servo": false, "drive": false},
  "drive": {"target_area_frac": 0.10, "k_ang": 1.5, "k_lin": 2.0,
            "max_ang": 1.0, "max_lin": 0.20, "deadzone": 0.02}
}
```

| キー | 説明 |
|---|---|
| `enabled` / `mode` | 有効無効 / 検出モード（off / aruco / color / face / qr） |
| `color` | 色モードの**名前付きプリセット**（red / orange / … / purple）。`color_rgb` が未設定のときの既定 |
| `color_rgb` | 色モードの**任意の対象色**（カラーパレットから取得した `#RRGGBB` または `[r,g,b]`）。設定時は `color` より優先 |
| `color_hue_tol` | `color_rgb` の色相許容幅（OpenCV H 0–179 の±半幅。大きいほど広く拾う） |
| `color_s_min` / `color_v_min` | 色モードの彩度・明度の下限（0–255）。下げるほど淡い/暗い色も拾う（誤検出増） |
| `min_area_frac` | 検出の最小サイズ（フレーム面積に対する割合）。これ未満の検出を全モードで除外（微小ノイズ・ALL の誤検出抑制） |
| `aruco_dict` | AR モードの辞書（例 `DICT_4X4_50`）。印刷したマーカーと一致が必要。`"ALL"` で代表的な全辞書を走査（少し重く・誤検出増）。検出器はキャッシュ |
| `speak` | 検出文字列を `/speech/say` に流すか |
| `hfov_deg` | カメラ水平画角（pixel → 角度の変換に使用） |
| `target_marker_id` | 追従を優先する AR ID（null＝最大面積） |
| `target_joints` | 首 policy が動かす関節・符号・ゲイン（任意設定） |
| `behaviors` | look_at / servo / drive の個別有効化 |
| `drive` | 追従の目標サイズ率・ゲイン・上限速度 |

### 起動時初期値とメッセージ型の選定

**起動時初期値**：smabo-brain は起動時に画像処理設定の初期値を読み込めます。

- `--vision-config <path.json>`（または環境変数 `SMABO_VISION_CONFIG`）で JSON ファイルを指定。中身は上の `/vision/config` の `data` と同形（**部分指定可**、欠けたキーは組み込み既定で補完）。
- 未指定なら組み込み既定（`mode=off`・検出無効・`behaviors.look_at=true`・首は `head_pan` のみ・tilt なし）で起動。
- 起動後は `/vision/config` で実行中に部分上書き。「**起動時初期値＋実行時上書き**」が brain 単体（WS）でも smabo-brain-ros（ROS）でも成立します。

**型の選定（なぜ String + JSON か）**：検出結果のような**データプレーンは標準型**（`vision_msgs/Detection2DArray`・`geometry_msgs/PoseStamped`）で相互運用性を確保する一方、設定のような**コントロールプレーンは `std_msgs/String`＋JSON** にしています。設定は mode/color/target_joints/behaviors/drive と異種・入れ子・将来追加が多く、これに合う標準 ROS メッセージ型が無いこと、1トピックに集約でき型変更なしでフィールド追加できること、rosbridge/Web から扱いやすいことが理由です。

> ROS 的には設定はノードパラメータが本来の場所なので、**smabo-brain-ros 側では `image_processor_node` の ROS 2 パラメータとしても公開**し、`ros2 param` で操作できるようにします（Web↔brain は String/JSON、ROS 側はパラメータ、の二段構え）。両者の初期値・上書きは `brain.vision.merge_config`（純ロジック）で同一に適用します。

### メッセージ定義（vision）

**`/vision/detections` — vision_msgs/Detection2DArray**（smabo-brain → web。smabo-brain-ros は ROS2 型）

```json
{
  "header": {"stamp": {"sec": 0, "nanosec": 0}, "frame_id": "camera"},
  "source_img_width": 640, "source_img_height": 480,
  "detections": [{
    "header": {"stamp": {"sec": 0, "nanosec": 0}, "frame_id": "camera"},
    "bbox": {"center": {"position": {"x": 320.0, "y": 180.0}, "theta": 0.0},
             "size_x": 96.0, "size_y": 96.0},
    "results": [{"hypothesis": {"class_id": "face", "score": 0.92}}]
  }]
}
```

> `class_id` は AR=マーカー番号、color=色名、face=`"face"`、qr=内容。`center.position` は**画素**座標。
> `source_img_width/height` は標準外の補助フィールド（消費側が画素→正規化する手掛かり）。

**`/vision/markers` — std_msgs/String**（AR 番号 / QR 内容。複数はカンマ区切り）

```json
{"data": "3,7"}
```

### policy（pixel→方向→各指令）

最大面積（または指定 AR ID）の検出を対象に、画素位置と画角から**ロボット座標系の方向ベクトル**
`(x=前, y=左, z=上)` を求め（`bbox_to_direction`）、各 behavior に変換します。

- **gaze → `/look_at`（PoseStamped）**：`position` に方向ベクトルをそのまま入れる
- **neck → `/servo/command`**：`pan = atan2(y, x)`、`tilt = atan2(z, hypot(x, y))`（config の関節・符号・ゲイン）
- **drive → `/cmd_vel`**：`angular.z = -k · u_n`（対象を水平中央へ）、`linear.x = k · (目標面積率 − 現面積率)`（bbox の見かけサイズを距離の代理に前後）。正面でないときは前進抑制、対象ロスト時は停止。

> 手動操作との競合：vision 有効時のみ各 policy が出力します。gaze は smabo-web の Face タブの手動 GazePad と同じ `/look_at`（app の follow モード）を共有するため、**vision の gaze が有効な間は Face タブの GazePad を無効化**して排他にします（「Vision が gaze を制御中」と表示）。neck / drive も同様に vision 有効時はその出力が優先されます。

---

> **以下 §1〜§8 は smabo-esp32（ファームウェア）の詳細**です。
> ESP32 は中継サーバ smabo-brain へ WebSocket **クライアント**として接続し
> （`ws://<brain-host>:<port>/esp32`）、アクチュエータ制御とセンサ取得を担います。
> 制御指令は smabo-web → smabo-brain 経由で届き、ホイール速度等は smabo-brain へ送ります。

## 1. モジュール構成

```
smabo-esp32/
├── main.py              # 起動エントリ・asyncio イベントループ
├── config.py            # 永続設定（RAM + config.json、デバウンス保存）・DEFAULTS
├── wifi_manager.py      # WiFi 接続・自動再接続
├── ws_client.py         # RFC 6455 WebSocket クライアント（smabo-brain へ接続・自動再接続、外部ライブラリ不要）
├── robot.py             # オーケストレータ（rosbridge プロトコル・モード管理）
├── pca9685.py           # PCA9685 PWM ドライバ（サーボ用 I2C）
├── servo_controller.py  # JointGroup（全サーボ共通）
├── random_motion.py     # グループ単位のランダム動作（タイミンググループ管理）
├── dc_motors.py         # TB6612 差動駆動（cmd_vel 受信・デッドマン停止）
├── encoder.py           # GPIO 割り込みによるエンコーダカウント
├── wheel_publisher.py   # エンコーダ → ホイール速度（/wheel_vel）送信。オドメトリ積分は smabo-brain 側
├── config.json          # 実機の差分設定（DEFAULTS へ deep-merge。WiFi / brain 接続先 等。git 管理外）
└── configs/             # ボード別 config.json テンプレート（後述 §8）
    ├── config.esp32-classic.json     # ESP32（無印）DevKit 38pin
    ├── config.esp32s3-devkitc1.json  # ESP32-S3-DevKitC-1 / DevKitM-1 系
    └── config.xiao-esp32s3.json      # Seeed XIAO ESP32-S3
```

> `config.json` は `config.py` の `DEFAULTS` に対する**差分のみ**を保持します（起動時に deep-merge）。
> ボードを変えるときは `configs/` の該当ファイルをデバイス直下に `config.json` としてコピーします。

---

## 2. クラス図

```mermaid
classDiagram
    direction TB

    class Config {
        +data : dict
        +get(path, default) any
        +set(path, value, persist)
        +update(partial, persist)
        +save_now()
        +mark_dirty(debounce_ms)
        +autosave_task() async
    }

    class WSClient {
        +host : str
        +port : int
        +path : str
        +on_message : callable
        +run() async
        +broadcast(text)
        -_handshake(reader, writer) async
        -_read_loop(reader, writer) async
    }

    class Robot {
        +cfg : Config
        +pca : PCA9685
        +ws  : WSClient
        +servo_group   : JointGroup
        +random_motion : RandomMotion
        +drive     : DiffDrive
        +encoders  : tuple
        +wheel_pub : WheelPublisher
        +start()
        +on_message(client, text)
        +apply_modes(modes)
        +publish(topic, msg)
        -_on_set_config(config_dict)
        -_reload_subsystems(changed_keys)
        -_joint_states_task() async
        -_reboot_after(ms, reasons) async
    }

    class PCA9685 {
        +i2c  : I2C
        +addr : int
        +set_freq(freq)
        +set_us(channel, us)
        +off(channel)
    }

    class JointGroup {
        +pca         : PCA9685
        +joints      : dict
        -_traj_queue : list
        +set_angle_deg(name, angle)
        +load_trajectory(names, points)
        +get_state() dict
        +run(dt) async
    }

    class RandomMotion {
        +group : JointGroup
        +cfg   : Config
        +run_group(group_name) async
        -_behavior() str
        -_group_cfg(name) dict
    }

    class DiffDrive {
        +cfg   : Config
        +left  : _Motor
        +right : _Motor
        +stby  : Pin
        +set_cmd_vel(linear_x, angular_z)
        +stop()
        +watchdog_task() async
    }

    class _Motor {
        +pwm  : PWM
        +in1  : Pin
        +in2  : Pin
        +drive(value)
        +stop()
    }

    class QuadEncoder {
        -_count : int
        +read() int
        +read_and_reset() int
    }

    class WheelPublisher {
        +cfg       : Config
        +enc_left  : QuadEncoder
        +enc_right : QuadEncoder
        -_last_ms  : int
        +run(publish) async
    }

    Robot --> Config         : 参照
    Robot --> WSClient       : 参照
    Robot --> PCA9685        : 参照
    Robot "1" *-- "0..1" JointGroup   : servo_group
    Robot "1" *-- "0..1" RandomMotion
    Robot "1" *-- "0..1" DiffDrive
    Robot "1" *-- "0..1" WheelPublisher
    JointGroup   --> PCA9685    : PWM 出力
    RandomMotion --> JointGroup : 角度指令
    RandomMotion --> Config     : 参照（毎ループ読み直し）
    DiffDrive "1" *-- "2" _Motor : left / right
    WheelPublisher --> QuadEncoder : カウント読み取り
    WheelPublisher --> Config      : 参照
    DiffDrive --> Config        : 参照
```

> **共通化ポイント**: 首・ハンド・アームを含む全サーボを `servo_group`（`JointGroup` の単一インスタンス）で管理します。
> ランダム動作のグループ分けは `RandomMotion` が担い、`JointGroup` 自体はグループを意識しません。
>
> **オドメトリの分担**: ESP32 はエンコーダから算出したホイール速度（`/wheel_vel`）を送るだけで、
> x/y/θ への積分と `nav_msgs/Odometry` の生成は smabo-brain 側で行います（IMU/GPS と融合できるようにするため）。

---

## 3. 非同期タスク構成

起動後に asyncio 上で動作するタスクの一覧です。
`Robot._tasks` で名前管理され、モード変更時に個別にキャンセル・再生成されます。

| タスク名 | コルーチン | 役割 | 起動条件 |
|---|---|---|---|
| `servo_follower` | `JointGroup.run()` | サーボ角度の速度制限追従・軌道キュー処理 | `modes.servos = true` |
| `random_<name>` | `RandomMotion.run_group(name)` | グループ単位のランダムタイマー（グループ数分起動） | `modes.servos = true` |
| `joint_states` | `Robot._joint_states_task()` | `/joint_states` 送信（MoveIt2連携用） | `modes.servos = true` |
| `drive_wd` | `DiffDrive.watchdog_task()` | cmd_vel デッドマン監視 | `dc_drive` or `encoder_drive` |
| `odom` | `WheelPublisher.run()` | エンコーダ読み取り + `/wheel_vel` 送信 | `modes.encoder_drive = true` |
| `autosave` | `Config.autosave_task()` | 設定デバウンス保存 | 常時 |
| `wifi_ka` | `wifi_manager.keepalive_task()` | WiFi 再接続監視 | 常時 |

> `random_<name>` のタスク名はグループ名から自動生成されます（例: `random_neck`, `random_hands`）。
> グループ数を変更すると `servos` モードが再起動され、新しいグループ数に合わせてタスクが再生成されます。

---

## 4. シーケンス図

> 以降の図で `WSClient` は ESP32 内の WebSocket クライアント層（`ws_client.py`）です。
> ESP32 と外部（`smabo-web` / `SBC` 等）の通信はすべて中継サーバ **smabo-brain** を経由します。
> 図中で外部アクターから `WSClient` への矢印は、実際には smabo-brain によって中継されたものです。
>
> **送信元 prefix 規約**: 各クライアントは publish するトピックに送信元 prefix を付けます
> （ESP32 → `/esp32`、smabo-web → `/web`、smabo-app → `/app`）。smabo-brain はこの prefix を
> **剥がしてから** canonical なトピック名で宛先へ再配信します。したがって ESP32 が物理的に送出する
> トピックは `/esp32/wheel_vel`・`/esp32/joint_states` ですが、クライアントは `/wheel_vel`・`/joint_states`
> として受け取ります。逆に ESP32 が受信する `/cmd_vel`・`/servo/command` は、smabo-web が送った
> `/web/cmd_vel`・`/web/servo/command` から brain が prefix を剥がしたものです。
> 図中の `/cmd_vel` 等は**剥がされた後の canonical 名**で表記しています。

### 4-1. 起動シーケンス

```mermaid
sequenceDiagram
    participant main
    participant Config
    participant WiFi as wifi_manager
    participant I2C/PCA as PCA9685
    participant WSClient
    participant Robot

    main->>Config: Config()
    Config->>Config: _load() — config.json を読み DEFAULTS とマージ
    main->>WiFi: connect(cfg)
    WiFi-->>main: WLAN オブジェクト

    main->>I2C/PCA: I2C() + PCA9685()
    main->>WSClient: WSClient(brain.host, brain.port, "/esp32", on_message)
    main->>Robot: Robot(cfg, pca, ws)

    main->>Robot: robot.start()
    Robot->>Robot: apply_modes(cfg.modes)
    Robot->>Robot: enable_servos / enable_drive

    main->>WSClient: asyncio.create_task(ws.run())  ← smabo-brain へ接続（自動再接続）
    main->>main: asyncio tasks: autosave, wifi_keepalive
    Note over main: イベントループ開始 (sleep forever)
```

---

### 4-2. WebSocket 接続確立（ESP32 → smabo-brain）

ESP32 はクライアントとして smabo-brain へ接続しに行きます（接続が切れたら自動再接続）。

```mermaid
sequenceDiagram
    participant WSClient as ESP32 (WSClient)
    participant Brain as smabo-brain

    loop run() — 切断時は 3 秒後に再接続
        WSClient->>Brain: TCP connect → HTTP GET /esp32 (Upgrade: websocket)
        WSClient->>WSClient: ランダム Sec-WebSocket-Key を生成
        Brain-->>WSClient: HTTP 101 Switching Protocols
        Note over WSClient,Brain: 以降 RFC 6455 フレームで双方向通信\n（client→server フレームはマスク必須）
        WSClient->>WSClient: _read_loop() でフレーム受信
    end
```

---

### 4-3. 走行制御 (cmd_vel)

```mermaid
sequenceDiagram
    participant Client
    participant WSClient
    participant Robot
    participant DiffDrive

    Client->>WSClient: {"op":"publish","topic":"/cmd_vel",\n"msg":{"linear":{"x":0.2},"angular":{"z":0.3}}}
    WSClient->>Robot: on_message(client, text)
    Robot->>Robot: _on_publish("/cmd_vel", msg)
    Robot->>DiffDrive: set_cmd_vel(0.2, 0.3)
    DiffDrive->>DiffDrive: 差動運動学 → v_l / v_r 正規化
    DiffDrive->>DiffDrive: left.drive(v_l),  right.drive(v_r)
    Note over DiffDrive: _last_cmd_ms を更新

    loop 100 ms ごと (watchdog_task)
        DiffDrive->>DiffDrive: ticks_diff > cmd_timeout?
        alt タイムアウト
            DiffDrive->>DiffDrive: stop()
        end
    end
```

---

### 4-4. サーボ手動制御 — 単一点 (JointTrajectory 1 点)

```mermaid
sequenceDiagram
    participant Client
    participant WSClient
    participant Robot
    participant JointGroup as servo_group

    Client->>WSClient: {"op":"publish","topic":"/servo/command",\n"msg":{"joint_names":["head_pan","arm_joint_1"],\n"points":[{"positions":[0.5,-0.2],"time_from_start":{"sec":0}}]}}
    WSClient->>Robot: on_message()
    Robot->>Robot: _on_publish("/servo/command", msg)
    Robot->>JointGroup: load_trajectory(names, points)
    JointGroup->>JointGroup: deadline = ticks_ms() + 0ms
    JointGroup->>JointGroup: _traj_queue = [(deadline, {head_pan:28.6°, arm_joint_1:-11.5°})]

    loop 20 ms ごと (servo_follower タスク)
        JointGroup->>JointGroup: deadline 到達 → _target 更新
        JointGroup->>JointGroup: max_speed 制限で _current を _target に近づける
        JointGroup->>PCA9685: set_us(channel, us)
    end
```

---

### 4-5. サーボ軌道制御 — 複数点 (MoveIt2 / time-parameterised)

```mermaid
sequenceDiagram
    participant SBC as SBC (MoveIt2)
    participant WSClient
    participant Robot
    participant JointGroup as servo_group

    SBC->>WSClient: {"op":"publish","topic":"/servo/command",\n"msg":{"joint_names":["arm_joint_1","arm_joint_2"],\n"points":[\n  {"positions":[0.0,0.0],"time_from_start":{"sec":0}},\n  {"positions":[0.5,0.3],"time_from_start":{"sec":1}},\n  {"positions":[1.0,0.6],"time_from_start":{"sec":2}}\n]}}
    WSClient->>Robot: on_message()
    Robot->>Robot: _on_publish("/servo/command", msg)
    Note over Robot: points が複数 → load_trajectory（時系列）
    Robot->>JointGroup: load_trajectory(names, points)
    JointGroup->>JointGroup: start_ms = ticks_ms()
    JointGroup->>JointGroup: _traj_queue = [(0ms,…),(1000ms,…),(2000ms,…)]

    loop 20 ms ごと (servo_follower タスク)
        JointGroup->>JointGroup: ticks_diff(now, deadline) >= 0 ?
        alt 次のポイントの時刻に到達
            JointGroup->>JointGroup: _target を該当ポイントの角度に更新
        end
        JointGroup->>JointGroup: max_speed 制限で _current を _target に追従
        JointGroup->>PCA9685: set_us(channel, us)
    end
```

> `time_from_start` は `load_trajectory()` 呼び出し時刻からの相対時間です。
> 各ポイントへの移動は `max_speed` (deg/s) の上限内でなめらかに追従します。

---

### 4-6. ナビゲーション連携（Nav2 + cmd_vel / odom）

ESP32 はホイール速度（`/wheel_vel`）のみを送り、smabo-brain がそれを積分して
`nav_msgs/Odometry`（`/odom`）を生成・配信します。covariance も smabo-brain が付与します。

```mermaid
sequenceDiagram
    participant PC
    participant SBC as SBC (ROS2 Nav2 + rosbridge)
    participant Brain as smabo-brain
    participant ESP32

    PC->>SBC: 目標位置 (geometry_msgs/PoseStamped)
    Note over SBC: Nav2 がパス計画・速度計算

    loop Nav2 制御ループ
        ESP32->>Brain: {"op":"publish","topic":"/esp32/wheel_vel","msg":{left,right,dt}}
        Brain->>Brain: /esp32 prefix を剥がす → ホイール速度を積分 → (x, y, θ)
        Brain->>SBC: {"op":"publish","topic":"/odom","msg":{nav_msgs/Odometry}}
        Note over SBC: /odom を受信して自己位置を更新
        SBC->>Brain: {"op":"publish","topic":"/cmd_vel","msg":{geometry_msgs/Twist}}
        Brain->>ESP32: /cmd_vel を中継（SBC は prefix 無しで送出）
        Note over ESP32: DiffDrive.set_cmd_vel() → モータ制御
    end

    Note over Brain,SBC: covariance は smabo-brain が付与するため\nNav2 がオドメトリの信頼度を正しく評価できる
```

---

### 4-7. ランダム動作（グループ独立タイマー）

```mermaid
sequenceDiagram
    participant Client
    participant WSClient
    participant Robot
    participant RM as RandomMotion
    participant JG as servo_group (JointGroup)

    Client->>WSClient: {"op":"set_config","config":{"servos":{"behavior":"random"}}}
    WSClient->>Robot: on_message()
    Note over Robot: behavior は次のループで即時反映（再起動不要）

    par neck グループ (independent timer)
        loop random interval [1.0, 3.0] s
            RM->>RM: cfg から neck グループ設定を読む
            RM->>JG: set_angle_deg("head_pan",  random angle)
            RM->>RM: sleep( random(1.0, 3.0) )
        end
    and hands グループ (independent timer)
        loop random interval [2.0, 5.0] s
            RM->>RM: cfg から hands グループ設定を読む
            RM->>JG: set_angle_deg("left_hand",  random angle)
            RM->>JG: set_angle_deg("right_hand", random angle)
            RM->>RM: sleep( random(2.0, 5.0) )
        end
    end
```

> グループ内のサーボは**同じ瞬間**に動き出しますが、目標角度はそれぞれ独立したランダム値です。
> グループ間のタイマーは完全に独立しており、自然にずれていきます。

---

### 4-8. 設定変更（ソフト設定 — サブシステム再起動のみ）

```mermaid
sequenceDiagram
    participant Client as Web 設定画面
    participant WSClient
    participant Robot
    participant Config

    Client->>WSClient: {"op":"set_config","config":{"servos":{"joints":{"head_pan":{"max_angle":80}}}}}
    WSClient->>Robot: on_message()
    Robot->>Robot: _on_set_config(config_dict)
    Robot->>Robot: _reboot_reasons() → [] (ピン変更なし)
    Robot->>Config: update({"servos":...})  ← deep-merge + mark_dirty
    Robot->>Robot: _reload_subsystems(["servos"])
    Robot->>Robot: _teardown_servos()  ← タスクキャンセル・インスタンス解放
    Robot->>Robot: enable_servos(True) ← 新設定で JointGroup + RandomMotion 再生成

    Note over Config: 2 秒後に autosave_task が config.json へ書き込み
```

---

### 4-9. 設定変更（ハード設定 — ピン変更 → 強制再起動）

```mermaid
sequenceDiagram
    participant Client as Web 設定画面
    participant WSClient
    participant Robot
    participant Config
    participant MCU as machine.reset()

    Client->>WSClient: {"op":"set_config","config":{"dc":{"pins":{"pwma":18}}}}
    WSClient->>Robot: on_message()
    Robot->>Robot: _on_set_config(config_dict)
    Robot->>Robot: _reboot_reasons() → ["dc.pins"]
    Robot->>Config: update({"dc":...})
    Robot->>Config: save_now()  ← 即時フラッシュ（再起動前に必ず保存）
    Robot->>Robot: asyncio.create_task(_reboot_after(500ms, reasons))
    Robot-->>Client: {"op":"notice","message":"Rebooting to apply: dc.pins"}
    Note over Client: UI に「再起動中...」を表示し再接続を試みる
    Robot->>MCU: (500 ms 後) machine.reset()
    MCU->>MCU: 新しいピン設定で起動
```

---

### 4-10. モード切り替え

```mermaid
sequenceDiagram
    participant Client
    participant WSClient
    participant Robot

    Client->>WSClient: {"op":"set_mode","modes":{"encoder_drive":true,"dc_drive":false}}
    WSClient->>Robot: on_message()
    Robot->>Robot: apply_modes(merged_modes)
    Note over Robot: encoder_drive と dc_drive の排他チェック
    Robot->>Robot: enable_servos(true)  ← モード変更なしなら再起動しない
    Robot->>Robot: disable_drive()  ← 既存タスクをキャンセル
    Robot->>Robot: enable_drive(with_encoder=true)
    Robot->>Config: update({"modes": ...})  ← 永続化
```

---

### 4-11. /joint_states 送信ループ

```mermaid
sequenceDiagram
    participant JointGroup as servo_group
    participant Robot
    participant Client as SBC / クライアント

    loop 1/joint_states_rate 秒ごと (デフォルト 20 Hz)
        Robot->>JointGroup: get_state()
        JointGroup-->>Robot: {"left_hand": 0.0, "right_hand": 0.0, "head_pan": 0.5, ...}
        Robot->>Client: {"op":"publish","topic":"/esp32/joint_states",\n"msg":{"name":[...],"position":[...],...}}
        Note over Robot,Client: brain が /esp32 を剥がし /joint_states として配信
    end
```

> `servos.joint_states_rate = 0` で無効化できます。`modes.servos = false` のときは送信しません。

---

### 4-12. ホイール速度送信ループ（/wheel_vel）

ESP32 はエンコーダのホイール速度を送るだけで、x/y/θ への積分は smabo-brain が行います。

```mermaid
sequenceDiagram
    participant QuadEncoder
    participant WheelPublisher
    participant Robot
    participant Brain as smabo-brain

    loop 1/publish_rate 秒ごと (デフォルト 20 Hz)
        WheelPublisher->>QuadEncoder: enc_left.read_and_reset()
        WheelPublisher->>QuadEncoder: enc_right.read_and_reset()
        WheelPublisher->>WheelPublisher: count → 距離 → 速度 (m/s)、実 dt を計測
        WheelPublisher->>Robot: publish("/wheel_vel", {left, right, dt})
        Robot->>Brain: {"op":"publish","topic":"/esp32/wheel_vel","msg":{...}}
        Note over Robot: Robot.publish() が送信元 prefix /esp32 を付与
        Brain->>Brain: /esp32 を剥がす → 積分 → /odom を生成・配信
    end
```

---

### 4-13. 設定の読み出し

```mermaid
sequenceDiagram
    participant Client as Web 設定画面
    participant WSClient
    participant Robot
    participant Config

    Client->>WSClient: {"op":"get_config"}
    WSClient->>Robot: on_message()
    Robot->>Config: cfg.data (全設定 dict)
    Robot-->>Client: {"op":"set_config","config":{...全設定...}}
```

---

## 5. WebSocket メッセージ仕様

### 接続情報

| 項目 | 値 |
|---|---|
| プロトコル | RFC 6455 WebSocket (テキストフレーム) |
| 接続形態 | ESP32 が **クライアント**として smabo-brain へ接続 |
| 接続先 | `ws://<brain-host>:<port>/esp32`（`config.brain.host` / `config.brain.port`、既定 `9090`） |
| フォーマット | UTF-8 JSON、1 メッセージ = 1 フレーム |
| 認証 | なし（信頼済み LAN 内利用前提） |

> 以下「クライアント → ESP32」「ESP32 → クライアント」は、いずれも smabo-brain を介した
> 論理的な送受信です（物理的な接続先は常に smabo-brain）。
>
> **送信元 prefix**: ESP32 が送出する publish は `Robot.publish()` で `/esp32` prefix が付きます
> （物理フレームは `/esp32/wheel_vel` 等）。smabo-brain がこの prefix を剥がし、canonical 名
> （`/wheel_vel`・`/joint_states`、`/wheel_vel` は積分後 `/odom`）でクライアントへ配信します。
> ESP32 が受信する `/cmd_vel`・`/servo/command` は、smabo-web 等が `/web` prefix 付きで送ったものを
> brain が剥がした後の canonical 名です。`set_config` / `get_config` / `notice` / `error` などの
> publish 以外の op には prefix は付きません。
> 5-1・5-2 の例は **canonical 名（剥がした後）** を基本に記載し、ESP32 送信側のみ物理 prefix を併記します。

---

### 5-1. クライアント → ESP32（受信）

#### `publish` — ロボット操作

| フィールド | 型 | 説明 |
|---|---|---|
| `op` | string | `"publish"` 固定 |
| `topic` | string | ROS トピック名 |
| `msg` | object | トピック型に対応した JSON |

---

**走行制御** `geometry_msgs/Twist`

```json
{
  "op": "publish",
  "topic": "/cmd_vel",
  "msg": {
    "linear":  {"x": 0.2,  "y": 0.0, "z": 0.0},
    "angular": {"x": 0.0,  "y": 0.0, "z": 0.3}
  }
}
```

| フィールド | 単位 | 範囲 |
|---|---|---|
| `linear.x` | m/s | `[-max_linear, +max_linear]` |
| `angular.z` | rad/s | `[-max_angular, +max_angular]` |

> `cmd_timeout` 秒以内にメッセージが届かない場合、モータは自動停止します。

---

**サーボ手動制御** `trajectory_msgs/JointTrajectory`

```json
{
  "op": "publish",
  "topic": "/servo/command",
  "msg": {
    "joint_names": ["head_pan", "arm_joint_1"],
    "points": [
      {
        "positions": [0.5, -0.2],
        "velocities": [],
        "time_from_start": {"sec": 1, "nanosec": 0}
      }
    ]
  }
}
```

| トピック | ルーティング先 |
|---|---|
| `/servo/command` | `servo_group` |

> - `joint_names` で対象サーボを指定。`servos.joints` に登録されていない名前は無視されます
> - `positions` の単位は **ラジアン**（ROS 標準）
> - 1点・複数点どちらも `load_trajectory()` で統一処理されます
> - 各点は `time_from_start` を絶対時刻に変換してキューに積み、`run()` ループで到達時刻になったら `_target` を更新します
> - 1点で `time_from_start=0` の場合は次の `run()` tick（≤20ms）で即時適用されます
> - `max_speed` 制限でなめらかに追従します（`0` = 即時移動）
> - `behavior` が `"random"` の場合でも手動コマンドは受け付けます（次のランダム発火で上書きされます）
> - `max_speed` (deg/s) による速度制限追従で移動します（`0` = 即時）

---

#### `set_mode` — モード切り替え

```json
{
  "op": "set_mode",
  "modes": {
    "servos":        true,
    "dc_drive":      false,
    "encoder_drive": true
  }
}
```

> `modes` は部分指定可。未指定のモードは現在値を維持します。
> `dc_drive` と `encoder_drive` は同時 `true` にできません（`encoder_drive` が優先）。

---

#### `set_config` — 設定変更

```json
{
  "op": "set_config",
  "config": {
    "servos": {
      "behavior": "random",
      "random_groups": [
        {"name": "neck",  "joints": ["head_pan"], "interval": [1.0, 3.0]},
        {"name": "hands", "joints": ["left_hand", "right_hand"], "interval": [2.0, 5.0]}
      ]
    }
  }
}
```

> - 送信した部分のみ deep-merge されます（省略したキーは変更なし）
> - `servos.behavior` / `random_groups[*].interval` は次のループで即時反映（再起動不要）
> - `servos.joints` や `random_groups` のグループ追加・削除は `servos` モードが自動再起動されます
> - ピン・バス系変更時は自動的に `machine.reset()` が実行されます（後述）

---

#### `get_config` — 設定読み出し

```json
{"op": "get_config"}
```

→ ESP32 から `set_config` 形式で全設定が返ります。

---

#### `subscribe` / `advertise` / `unsubscribe`

rosbridge_suite との互換性のために受け付けます（内部動作への影響なし）。
ESP32 の送信（物理フレームは `/esp32/joint_states` / `/esp32/wheel_vel`）は `subscribe` なしでも smabo-brain へ送られます。

---

### 5-2. ESP32 → クライアント（送信）

#### `publish` — 関節状態 `sensor_msgs/JointState`

```json
{
  "op": "publish",
  "topic": "/esp32/joint_states",
  "msg": {
    "header": {"stamp": {"sec": 1234, "nanosec": 0}, "frame_id": ""},
    "name":     ["left_hand", "right_hand", "head_pan",
                 "arm_joint_1", "arm_joint_2", "arm_joint_3", "arm_joint_4"],
    "position": [0.0, 0.0, 0.5, 0.0, 0.0, 0.0, 0.0],
    "velocity": [0.0, 0.0, 0.0, 0.0, 0.0, 0.0, 0.0],
    "effort":   [0.0, 0.0, 0.0, 0.0, 0.0, 0.0, 0.0]
  }
}
```

> ESP32 は `/esp32/joint_states` として送出し、smabo-brain が `/esp32` を剥がして `/joint_states` で配信します。
> `position` の単位は **ラジアン**（ROS 標準）。デフォルト **20 Hz** で送信。
> `servos.joint_states_rate` で変更可（`0` で無効）。`modes.servos = true` のときのみ送信。

---

#### `publish` — ホイール速度 `/wheel_vel`

ESP32 はエンコーダから求めた左右ホイール速度（m/s）と実測の積分間隔 `dt`（s）を送ります。
これを受けた smabo-brain が x/y/θ を積分し、`nav_msgs/Odometry`（`/odom`）を生成して配信します。
（オドメトリの積分を上位側に置くことで、IMU/GPS との融合が可能になります）

```json
{
  "op": "publish",
  "topic": "/esp32/wheel_vel",
  "msg": {
    "left":  0.182,
    "right": 0.205,
    "dt":    0.050
  }
}
```

| フィールド | 単位 | 説明 |
|---|---|---|
| `left` | m/s | 左ホイールの周速度 |
| `right` | m/s | 右ホイールの周速度 |
| `dt` | s | 前回送信からの実測経過時間（brain 側の積分に使用） |

> ESP32 は `/esp32/wheel_vel` として送出し、smabo-brain が `/esp32` を剥がして積分後 `/odom` で配信します。
> デフォルト **20 Hz** で送信（`encoder.publish_rate` で変更可・即時反映）。
> `encoder_drive` モードが無効のときは送信しません。
> `nav_msgs/Odometry` 形式・covariance（`encoder.covariance.*` 由来）の生成は smabo-brain 側で行います。

---

#### `set_config` — get_config レスポンス

```json
{"op": "set_config", "config": { "...全設定..." }}
```

---

#### `notice` — 再起動通知

```json
{
  "op": "notice",
  "message": "Rebooting to apply pin/hw changes: dc.pins"
}
```

> このメッセージ受信後 約 500 ms で ESP32 が再起動します。
> Web 側は再接続ループを開始してください（再起動所要時間は約 3–5 秒）。

---

#### `error` — エラー通知

```json
{"op": "error", "message": "説明文"}
```

---

## 6. 設定項目一覧

### WiFi

| キー | 型 | デフォルト | 説明 |
|---|---|---|---|
| `wifi.ssid` | string | `"your-ssid"` | 接続先 SSID |
| `wifi.password` | string | `"your-password"` | パスワード |
| `wifi.hostname` | string | `"esp32-robot"` | mDNS ホスト名 |

> WiFi 設定は初回のみ `config.json` を直接書き込んで設定することを推奨します。
> WebSocket 経由での変更は再起動後に接続できなくなるリスクがあります。

### 接続先 brain（WebSocket）

ESP32 はここで指定した smabo-brain へクライアントとして接続します（パスは `/esp32` 固定）。

| キー | 型 | デフォルト | 説明 |
|---|---|---|---|
| `brain.host` | string | `"192.168.1.100"` | smabo-brain のホスト / IP（**実環境に合わせて要設定**） |
| `brain.port` | int | `9090` | smabo-brain の待ち受けポート |

### I2C / PCA9685

| キー | 型 | デフォルト | 説明 |
|---|---|---|---|
| `i2c.sda` | int | `21` | SDA ピン番号 |
| `i2c.scl` | int | `22` | SCL ピン番号 |
| `i2c.freq` | int | `400000` | クロック周波数 (Hz) |
| `pca9685.address` | int | `0x40` | I2C アドレス |
| `pca9685.freq` | int | `50` | PWM 周波数 (Hz)。サーボ標準は 50 Hz |

### モード

| キー | 型 | デフォルト | 説明 |
|---|---|---|---|
| `modes.servos` | bool | `true` | サーボ制御（首・ハンド・アームを含む全サーボ） |
| `modes.dc_drive` | bool | `false` | DCモータ走行有効 |
| `modes.encoder_drive` | bool | `false` | エンコーダ付き走行有効 |

### サーボ共通スペック

各サーボ設定（`servos.joints.*`）が持つフィールドです。

| フィールド | 型 | 説明 |
|---|---|---|
| `channel` | int | PCA9685 チャンネル番号 (0–15) |
| `min_angle` | float | 最小角度 (deg) |
| `max_angle` | float | 最大角度 (deg) |
| `min_us` | int | 最小パルス幅 (µs)。デフォルト `500` |
| `max_us` | int | 最大パルス幅 (µs)。デフォルト `2500` |
| `init_angle` | float | 起動時の初期角度 (deg) |
| `max_speed` | float | 最大角速度 (deg/s)。`0` = 即時移動 |

### サーボ（`servos`）

首・ハンド・アームを含む全サーボを一括管理します。

| キー | 型 | デフォルト | 説明 |
|---|---|---|---|
| `servos.behavior` | string | `"manual"` | `"manual"` / `"random"` |
| `servos.joints` | dict | 下記参照 | 全サーボ定義。`joint名 → servo spec` |
| `servos.random_groups` | list | 下記参照 | ランダム動作のタイミンググループ定義 |
| `servos.joint_states_rate` | float | `20.0` | `/joint_states` 送信レート (Hz)。`0` で無効 |

**デフォルトの `servos.joints`**

| キー | デフォルト |
|---|---|
| `servos.joints.left_hand` | ch=0, 0–90°, max_speed=0（即時） |
| `servos.joints.right_hand` | ch=1, 0–90°, max_speed=0（即時） |
| `servos.joints.head_pan` | ch=2, ±90°, max_speed=120 |
| `servos.joints.arm_joint_1` | ch=3, ±90°, max_speed=90 |
| `servos.joints.arm_joint_2` | ch=4, ±90°, max_speed=90 |
| `servos.joints.arm_joint_3` | ch=5, ±90°, max_speed=90 |
| `servos.joints.arm_joint_4` | ch=6, ±90°, max_speed=90 |

> 首はパン（`head_pan`）のみがデフォルトです（チルトはデフォルトから削除）。
> 首チルトが必要な場合は `servos.joints.head_tilt` を追加してください。

> アームの軸数を変えるには `servos.joints` に `arm_joint_N` エントリを追加・削除します。`set_config` で変更後、`servos` モードが自動再起動されます。

**`servos.random_groups` — グループ定義**

| フィールド | 型 | 説明 |
|---|---|---|
| `name` | string | グループ識別名（タスク名 `random_<name>` に使用） |
| `joints` | list of string | このグループに属するサーボ名のリスト |
| `interval` | [float, float] | ランダム発火の待機時間範囲 (s)。`[最小, 最大]` |
| `saccade_prob` | float | 大きく素早い注視（サッカード）の確率 0–1（既定 0.18） |
| `drift` | float | ドリフト幅（可動域に対する割合・ガウス step、既定 0.07） |
| `center_pull` | float | 中立角への引き戻しの強さ 0–1（既定 0.12） |
| `drift_speed` | float | ドリフト速度（`max_speed` に対する割合、既定 0.4） |
| `long_pause_prob` | float | 時々の長い静止（settle）の確率 0–1（既定 0.22） |

> `saccade_prob` 以降は**生物的ランダム動作のチューニング**用（すべて任意・即時反映）。
> 省略時は既定値。サッカード時はフル `max_speed`、ドリフト時は `max_speed × drift_speed`。
> 動作モデル：通常は中立角へ引き戻しつつ微小ガウス step でゆらぎ（ドリフト）、
> 時々サッカードで大きく素早く動く。`max_speed`=0 のサーボはランダム時 120°/s で滑らかに動く。

**デフォルトのグループ構成**

```
neck  グループ: ["head_pan"]                — 1.0〜3.0 秒ごとに発火
hands グループ: ["left_hand","right_hand"] — 2.0〜5.0 秒ごとに同時発火
```

> グループに属さないサーボは手動コマンド（`/servo/command`）でのみ動きます。

### DCモータ

> デフォルトは**ESP32（無印）DevKit 38pin** 向け。左ヘッダの出力可能な連続パッド
> `32,33,25,26,27,14,12` に TB6612FNG 制御 7 本を**基板の印字順**で割り当てており、
> 剥く前の連結ジャンプワイヤを一直線に挿せます。ESP32-S3 / XIAO は `configs/` のプリセットを使用してください。

| キー | 型 | デフォルト | 説明 |
|---|---|---|---|
| `dc.pins.pwma` | int | `32` | 左モータ PWM |
| `dc.pins.ain2` | int | `33` | 左モータ IN2 |
| `dc.pins.ain1` | int | `25` | 左モータ IN1 |
| `dc.pins.stby` | int | `26` | TB6612 STBY ピン |
| `dc.pins.bin1` | int | `27` | 右モータ IN1 |
| `dc.pins.bin2` | int | `14` | 右モータ IN2 |
| `dc.pins.pwmb` | int | `12` | 右モータ PWM |
| `dc.pwm_freq` | int | `1000` | PWM 周波数 (Hz) |
| `dc.max_linear` | float | `0.30` | 最大直進速度 (m/s) |
| `dc.max_angular` | float | `1.50` | 最大旋回速度 (rad/s) |
| `dc.wheel_radius` | float | `0.030` | 車輪半径 (m) |
| `dc.wheel_separation` | float | `0.150` | 車輪間距離 (m) |
| `dc.invert_left` | bool | `false` | 左モータ回転方向反転 |
| `dc.invert_right` | bool | `false` | 右モータ回転方向反転 |
| `dc.cmd_timeout` | float | `0.5` | デッドマンタイムアウト (s) |

### エンコーダ / オドメトリ

| キー | 型 | デフォルト | 説明 |
|---|---|---|---|
| `encoder.left.a` | int | `34` | 左エンコーダ A 相ピン |
| `encoder.left.b` | int | `35` | 左エンコーダ B 相ピン |
| `encoder.right.a` | int | `36` | 右エンコーダ A 相ピン |
| `encoder.right.b` | int | `39` | 右エンコーダ B 相ピン |
| `encoder.cpr` | int | `1440` | 車輪 1 回転あたりのカウント数 |
| `encoder.publish_rate` | float | `20.0` | /wheel_vel 送信レート (Hz) |
| `encoder.odom_frame` | string | `"odom"` | odom の frame_id |
| `encoder.base_frame` | string | `"base_link"` | child_frame_id |
| `encoder.covariance.pose_xx` | float | `0.001` | x位置分散 (m²) |
| `encoder.covariance.pose_yy` | float | `0.001` | y位置分散 (m²) |
| `encoder.covariance.pose_aa` | float | `0.001` | yaw分散 (rad²) |
| `encoder.covariance.twist_vv` | float | `0.001` | 線速度分散 ((m/s)²) |
| `encoder.covariance.twist_ww` | float | `0.001` | 角速度分散 ((rad/s)²) |

---

## 7. 設定変更の反映ルール

`set_config` で送られた内容は以下のルールで処理されます。

### 即時反映（再起動不要・サブシステム再起動なし）

ループ内で毎回 Config から読み直すため、変更は次の処理サイクルで自動反映されます。

| 設定 | 反映タイミング |
|---|---|
| `servos.behavior` | 各ランダムグループの次のループ開始時 |
| `servos.random_groups[*].interval` | 現在の sleep 終了後（次の待機から新しい範囲が適用） |
| `servos.random_groups[*].joints` | 次のランダム発火タイミングで反映 |
| `servos.joint_states_rate` | 次の /joint_states 送信後 |
| `dc.cmd_timeout` | 次の watchdog チェック (100 ms 以内) |
| `encoder.publish_rate` | 次の /wheel_vel 送信後 |
| `encoder.covariance.*` | ESP32 側では不使用（smabo-brain が `get_config` 経由で取得し /odom に付与） |

### 即時反映（サブシステム再起動あり）

設定反映のためにサブシステムのタスクをキャンセルし、新設定でインスタンスを再生成します。
`servos` 再起動中はサーボが初期角度に戻ります（約 1 フレーム）。

| 変更キー | 再起動されるサブシステム | 具体的なトリガー例 |
|---|---|---|
| `servos.*` | `servo_follower`, `random_*` 全タスク, `joint_states` | サーボのチャンネル・角度範囲変更、グループ追加・削除、アーム軸の追加・削除 |
| `dc.*`（`pins` 以外） | `drive_wd`, `odom` | 速度上限・反転設定変更 |
| `encoder.*`（ピン以外） | `drive_wd`, `odom` | CPR 値変更 |

### 強制再起動（`machine.reset()`）

ピン割り当て・バスパラメータはペリフェラルの再初期化が必要なため、
設定を即時保存してから ESP32 をリセットします。

| 変更キー | 理由 |
|---|---|
| `i2c.*` | `machine.I2C` の再生成が必要 |
| `pca9685.*` | I2C バス上のデバイス再初期化 |
| `wifi.*` | `network.WLAN` の再接続（**下記注意参照**） |
| `dc.pins.*` | `machine.PWM` / `machine.Pin` の再生成 |
| `encoder.left.*` | `machine.Pin` + IRQ の再設定 |
| `encoder.right.*` | 同上 |

> **WiFi 設定変更の注意**: WebSocket は WiFi の上に乗っているため、SSID/Password を
> WebSocket 経由で変更すると再起動後に接続できなくなるリスクがあります。
> **WiFi 設定は初回のみ `config.json` を直接書き込んで設定し、以後は変更しない運用を推奨します。**
> 変更が必要な場合はシリアル(USB)経由で `config.json` を直接編集してください。

**再起動フロー:**
1. `config.json` に即時保存（`save_now()`）
2. `{"op":"notice","message":"Rebooting to apply: ..."}` を送信
3. 500 ms 後に `machine.reset()`
4. 起動後に新設定が自動的に読み込まれる

---

## 8. ハードウェア構成メモ

### PWM バスの分離

```
PCA9685 (I2C)  ←→  サーボ全軸（首・ハンド・アーム）  @ 50 Hz
ESP32 LEDC PWM ←→  DCモータドライバ（TB6612）        @ 1 kHz
```

> PCA9685 の PWM 周波数は 16ch 共通のため、サーボ(50 Hz)とモータ(1 kHz)を
> 同一デバイスに混在させると両立しません。

### エンコーダピンの注意

- GPIO **34–39** は入力専用・内部プルアップ無し → **外部プルアップ抵抗が必須**
- ソフトウェア IRQ カウントのため高速回転では取りこぼしが発生します
- 高精度が必要な場合は ESP32 PCNT バインディング入りカスタムファームウェアを推奨

### デフォルト PCA9685 チャンネル割り当て

| ch | `servos.joints` のキー名 | デフォルト用途 |
|---|---|---|
| 0 | `left_hand` | 左ハンド |
| 1 | `right_hand` | 右ハンド |
| 2 | `head_pan` | 首 パン |
| 3 | `arm_joint_1` | アーム 第1軸 |
| 4 | `arm_joint_2` | アーム 第2軸 |
| 5 | `arm_joint_3` | アーム 第3軸 |
| 6 | `arm_joint_4` | アーム 第4軸 |

### ボード別 DC ピンプリセット（`configs/`）

TB6612FNG の制御 7 本（`PWMA → AIN2 → AIN1 → STBY → BIN1 → BIN2 → PWMB`）と I2C を、
**ヘッダ上で隣り合うパッド**に割り当てたボード別テンプレートです。使うボードのファイルを
デバイス直下に `config.json` としてコピーするだけで、起動時に `DEFAULTS` へ deep-merge されます。
DC を使うには `"modes": {"dc_drive": true}` を追記して有効化します。

| ボード | ファイル | DC 7本 (PWMA→PWMB) | I2C (SCL / SDA) |
|---|---|---|---|
| ESP32（無印）DevKit 38pin | `config.esp32-classic.json` | 32, 33, 25, 26, 27, 14, 12 | 22 / 21 |
| ESP32-S3-DevKitC-1 / M-1 系 | `config.esp32s3-devkitc1.json` | 4, 5, 6, 7, 15, 16, 17 | 10 / 11 |
| Seeed XIAO ESP32-S3 | `config.xiao-esp32s3.json` | 1, 2, 3, 4, 5, 6, 43 (D0–D6) | 9(D10) / 8(D9) |

> 無印 ESP32 のデフォルト（`config.py` の `DEFAULTS`）は `config.esp32-classic.json` と同じピン並びです。
> GPIO 34–39 は入力専用のためモータ出力には使いません。互換クローンは印字順が異なる場合があるので、
> 基板のシルク印刷と必ず照合してください。

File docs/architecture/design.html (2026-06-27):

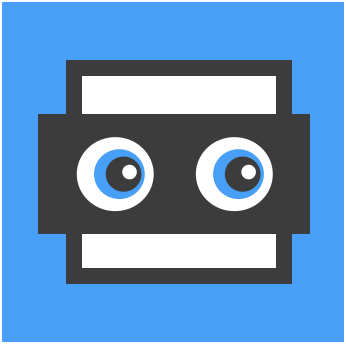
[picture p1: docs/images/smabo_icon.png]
smabo
 smabo

Design

# smabo システム設計

smabo（スマホロボット）システム全体の構成と、smabo-esp32 ファームウェアの詳細設計。

- 対象: smabo（スマホロボット）システム全体（smabo-app / smabo-web / smabo-brain / smabo-esp32 / smabo-brain-ros）
- 通信プロトコル: rosbridge v2.0 互換 WebSocket JSON。中継サーバ smabo-brain を中心としたハブ&スポーク構成
- 設定系: config / mode は smabo-web ↔ smabo-esp32 の REST 直通（smabo-brain を経由しない）
- 更新日: 2026-06-25

本ドキュメントは、smabo システム全体の構成（システム全体構成 / コンポーネント概要）と、 各コンポーネントのうち最も実装詳細の多い smabo-esp32（ファームウェア）の詳細（§1〜§8）をまとめます。

## 目次#

- システム全体構成
  - コンポーネント構成
  - 通信トポロジ
  - 通信モデル
  - 送信元 prefix 規約
  - 主要トピックとデータフロー
  - WebSocket エンドポイントとルーティング
  - 各クライアントの送受信トピック（WebSocket 全網羅）
  - WebSocket 通信シーケンス（app を含む全経路）
  - メッセージ定義（app / web）
- コンポーネント概要
- 画像処理（物体検出と追従）
  - データフロー
  - 処理モード
  - コンポーネントと配置
  - 制御メッセージ（/vision/config）
  - 起動時初期値とメッセージ型の選定
  - メッセージ定義（vision）
  - policy（pixel→方向→各指令）
- smabo-esp32（ファームウェア）詳細
  1. モジュール構成
  2. クラス図
  3. 非同期タスク構成
  4. シーケンス図
  5. WebSocket メッセージ仕様
  6. 設定項目一覧
  7. 設定変更の反映ルール
  8. ハードウェア構成メモ

## システム全体構成#

smabo は、中継サーバ smabo-brain を中心に各コンポーネントが WebSocket クライアントとして ぶら下がるハブ&スポーク構成です。各コンポーネントは smabo-brain の宛先だけを知っていればよく、 相互の直接接続は持ちません（設定系の REST 直通を除く）。

### コンポーネント構成#

コンポーネント | 役割 | 実装 | smabo-brain への接続
smabo-app | smabo の「顔（目）」とスマホセンサ（IMU / GPS / カメラ / ウェイクワード検出＋音声録音） | Flutter（スマートフォン） | WS /
smabo-web | 制御 UI・テレメトリ可視化・設定 | React / TypeScript（ブラウザ） | WS /ui（＋ ESP32 へ設定を REST 直）
smabo-brain | 中継ハブ＋マイコンでできない上位処理（オドメトリ積分等） | Python / aiohttp（PC / SBC） | サーバ（待受 :9090）
smabo-esp32 | アクチュエータ制御・センサ取得 | MicroPython（ESP32 系） | WS /esp32
smabo-brain-ros | ROS 2 連携（rosbridge_suite / Nav2 / MoveIt2） | ROS 2（SBC） | rosbridge（WS :9090）

### 通信トポロジ#

graph TB
    app["smabo-app（顔・センサ）"]
    web["smabo-web（制御UI）"]
    esp32["smabo-esp32（アクチュエータ／センサ）"]
    brain{{"smabo-brain　中継ハブ :9090"}}
    ros["smabo-brain-ros（Nav2 / MoveIt2）"]

    app <--> |"WS /（/app prefix）"| brain
    web <--> |"WS /ui（/web prefix）"| brain
    esp32 <--> |"WS /esp32 prefix"| brain
    web -.-> |"REST /config /mode（直通）"| esp32
    brain <--> |"rosbridge で ROS2 連携"| ros

### 通信モデル#

項目 | 内容
プロトコル | RFC 6455 WebSocket、UTF-8 JSON（rosbridge v2.0 互換）、1 メッセージ = 1 フレーム
待受 | smabo-brain が :9090 でサーバ。接続元ごとにパスを分ける（app=/、web=/ui、esp32=/esp32）
設定系 | config / mode は smabo-web ↔ smabo-esp32 の REST 直通（smabo-brain を経由しない）
ROS 2 連携 | smabo-brain-ros 構成では rosbridge_server（:9090）が WS ↔ ROS 2 を相互変換
認証 | なし（信頼済み LAN 内利用前提）

### 送信元 prefix 規約#

各クライアントは publish するトピックに送信元 prefix を付けて送ります （smabo-app → /app、smabo-web → /web、smabo-esp32 → /esp32）。 smabo-brain はこの prefix を剥がしてから canonical なトピック名で宛先へ再配信します （例: esp32 が送る /esp32/wheel_vel → 積分後 /odom、web が送る /web/cmd_vel → /cmd_vel）。 受信側は常に prefix 無しの canonical 名で受け取ります。 set_config / get_config / call_service など publish 以外の op には prefix は付きません。

### 主要トピックとデータフロー#

トピック | 型 | 送信元 → 宛先 | 内容
/cmd_vel | geometry_msgs/Twist | smabo-web / Nav2 → smabo-esp32 | 走行速度指令
/wheel_vel → /odom | （esp32 独自）→ nav_msgs/Odometry | esp32 → brain で積分 → web / Nav2 | ホイール速度 → オドメトリ
/servo/command | trajectory_msgs/JointTrajectory | smabo-web / MoveIt2 → smabo-esp32 | サーボ軌道指令
/joint_states | sensor_msgs/JointState | smabo-esp32 → web / MoveIt2 | 関節角度
/scan | sensor_msgs/LaserScan | smabo-esp32（LD06）→ brain → Nav2 | ライダ
/imu/data・/gps/fix | 各標準型 | smabo-app → smabo-web | スマホセンサ
カメラ映像（WebRTC, H.264/VP8） | — | smabo-app → smabo-brain（web へはプレビュー時のみ中継） | カメラ
/look_at・/expression・/speech/say | — | smabo-web → smabo-app | 顔（目）・発話の制御
/speech/audio | audio_common_msgs/AudioData（base64 WAV） | smabo-app → smabo-brain | wake 後に録音した発話音声（brain が STT）
/speech/recognized | std_msgs/String | smabo-brain → smabo-web | 音声認識結果（brain が STT した文字列）

### WebSocket エンドポイントとルーティング#

smabo-brain は接続元ごとにパスを分けてサーバ（:9090）として待ち受け、受け取った publish を 送信元 prefix を剥がして canonical 名で適切な宛先へ中継します。

エンドポイント | 接続元 | smabo-brain の処理
/ | smabo-app | app の publish（/app prefix）を剥がして smabo-web（UI）へ中継。ただし /webrtc/*（offer/ICE）と /speech/audio は smabo-brain が消費し（前者は WebRTC ピア、後者は STT）、web へは中継しない
/ui | smabo-web | publish（/web prefix）を剥がし、/speech/say・/expression・/look_at は smabo-app へ、/vision/config・/webrtc/* は smabo-brain が消費、それ以外は smabo-esp32 へ。publish 以外の op（set_config / get_config / set_mode 等）は smabo-esp32 へ
/esp32 | smabo-esp32 | publish（/esp32 prefix）を剥がし、/wheel_vel は積分して /odom を UI へ、それ以外は UI へ。esp32 が push する set_config は brain のオドメトリ同期にのみ使用

「web → app」へ流れるのは /speech/say・/expression・/look_at の3つだけです （brain.topics.APP_TOPICS）。/vision/config と /webrtc/*（プレビュー/シグナリング）は smabo-brain が消費し、残りの smabo-web の publish が smabo-esp32 宛になります。

### 各クライアントの送受信トピック（WebSocket 全網羅）#

smabo-app（パス /、publish には /app prefix を付与）

方向 | トピック | 型
送信（app → brain → web） | /imu/data | sensor_msgs/Imu
送信 | /gps/fix | sensor_msgs/NavSatFix
送信（app → brain、STT 用） | /speech/audio（wake 後の録音音声、base64 WAV） | audio_common_msgs/AudioData
送信（WebRTC、app → brain） | カメラ映像 + /webrtc/offer・/webrtc/app_ice（シグナリング） | —
受信（WebRTC、brain → app） | /webrtc/answer | —
受信（web → brain → app） | /look_at | geometry_msgs/PoseStamped
受信 | /expression | std_msgs/Int32
受信 | /speech/say | std_msgs/String

smabo-web（パス /ui、publish には /web prefix を付与）

方向 | トピック | 相手
送信 | /cmd_vel・/servo/command・/ping・（Nav2 用 /initialpose・/goal_pose） | → smabo-esp32
送信 | /look_at・/expression・/speech/say | → smabo-app
送信（非 publish op） | get_config・set_config・set_mode | → smabo-esp32（※設定は通常 REST 直通を使用）
送信（WebRTC プレビュー） | /webrtc/preview（ON/OFF）・/webrtc/web_answer・/webrtc/web_ice | → smabo-brain
受信（app 由来） | /imu/data・/gps/fix | ← smabo-app
受信（brain 由来） | /speech/recognized（brain が STT した文字列） | ← smabo-brain
受信（WebRTC 中継・プレビュー時のみ） | カメラ映像 + /webrtc/web_offer | ← smabo-brain
受信（esp32 由来） | /odom（/wheel_vel を積分）・/joint_states・/scan・/pong・notice・error | ← smabo-esp32

smabo-esp32（パス /esp32、publish には /esp32 prefix を付与。メッセージ詳細は §5）

方向 | トピック | 型
送信 | /wheel_vel（→ brain で /odom に積分） | left / right / dt
送信 | /joint_states | sensor_msgs/JointState
送信 | /scan（LD06、modes.lidar 時） | sensor_msgs/LaserScan
送信 | /pong（/ping のエコー）・set_config・notice・error | std_msgs/String 他
受信 | /cmd_vel | geometry_msgs/Twist
受信 | /servo/command | trajectory_msgs/JointTrajectory
受信 | /ping | std_msgs/String

### WebSocket 通信シーケンス（app を含む全経路）#

sequenceDiagram
    participant app as smabo-app
    participant brain as smabo-brain
    participant web as smabo-web
    participant esp32 as smabo-esp32

    Note over app,esp32: ① スマホセンサ（app → web）
    app->>brain: publish /app/imu/data・/app/gps/fix …
    brain->>web: /app を剥がし /imu/data・/gps/fix を配信
    Note over app,brain: カメラ映像は WebRTC（app → brain、シグナリングは /webrtc/*）

    Note over app,esp32: ② 顔・発話の制御（web → app）
    web->>brain: publish /web/look_at（/expression・/speech/say）
    brain->>app: APP_TOPICS なので /look_at を app へ配信

    Note over app,esp32: ③ 走行・サーボ（web → esp32）
    web->>brain: publish /web/cmd_vel・/web/servo/command
    brain->>esp32: /web を剥がし /cmd_vel・/servo/command を配信

    Note over app,esp32: ④ ロボット状態（esp32 → web）
    esp32->>brain: publish /esp32/wheel_vel・/esp32/joint_states・/esp32/scan
    brain->>web: /wheel_vel を積分して /odom、他は canonical 名で配信

### メッセージ定義（app / web）#

rosbridge v2.0 互換の JSON です（{"op":"publish","topic":...,"msg": <下記>} の msg 部分）。 すべての header は {"stamp":{"sec":<int>,"nanosec":<int>}, "frame_id":<string>} 形式です。 smabo-esp32 が扱う /cmd_vel・/servo/command・/joint_states・/wheel_vel の定義は §5 を参照してください。

/imu/data — sensor_msgs/Imu（smabo-app → smabo-web）

{
  "header": {"stamp": {"sec": 0, "nanosec": 0}, "frame_id": "imu_link"},
  "orientation": {"x": 0.0, "y": 0.0, "z": 0.0, "w": 1.0},
  "orientation_covariance": [0,0,0, 0,0,0, 0,0,0],
  "angular_velocity": {"x": 0.0, "y": 0.0, "z": 0.0},
  "angular_velocity_covariance": [0,0,0, 0,0,0, 0,0,0],
  "linear_acceleration": {"x": 0.0, "y": 0.0, "z": 9.81},
  "linear_acceleration_covariance": [0,0,0, 0,0,0, 0,0,0]
}

/gps/fix — sensor_msgs/NavSatFix（smabo-app → smabo-web）

{
  "header": {"stamp": {"sec": 0, "nanosec": 0}, "frame_id": "gps"},
  "status": {"status": 0, "service": 1},
  "latitude": 35.681,
  "longitude": 139.767,
  "altitude": 40.0,
  "position_covariance": [c,0,0, 0,c,0, 0,0,c],
  "position_covariance_type": 1
}

position_covariance の対角 c は水平精度の二乗（horizontalAccuracy²）。 status.status=0（FIX）/ service=1（GPS）、position_covariance_type=1（APPROXIMATED）。

カメラ映像 — WebRTC（smabo-app → smabo-brain）

カメラ映像は WebRTC で smabo-app から smabo-brain へ送られます。映像メディア本体は P2P（ローカル WiFi のホスト候補のみ、STUN/TURN なし）で流れ、/camera/image/compressed のような WebSocket トピックは使用しません。シグナリング（SDP / ICE 交換）だけが brain の WebSocket を経由します。

トピック | 向き | 内容
/webrtc/offer | app → brain | オファー SDP（{"data": "<JSON: sdp/type>"}）
/webrtc/answer | brain → app | アンサー SDP（brain の ICE 候補を SDP に同梱）
/webrtc/app_ice | app → brain | app の ICE 候補

smabo-brain は受信した映像からフレームを取り出して画像処理（§「画像処理」参照）に通し、 smabo-web がプレビューを ON にしている間だけ、同じ映像を /webrtc/web_offer で web へ中継します。

/look_at — geometry_msgs/PoseStamped（smabo-web → smabo-app、視線追従の目標）

{
  "header": {"stamp": {"sec": 0, "nanosec": 0}, "frame_id": "base_link"},
  "pose": {
    "position":    {"x": 1.0, "y": -0.3, "z": 0.2},
    "orientation": {"x": 0.0, "y": 0.0, "z": 0.0, "w": 1.0}
  }
}

position を方向ベクトルとして解釈します（REP-103: x=前 / y=左 / z=上）。 smabo-app は gazeX = -y/x・gazeY = -z/x で画面上の視線方向へ変換します（pose 無しの bare Pose も受理）。

/expression — std_msgs/Int32（smabo-web → smabo-app、表情ID）

{"data": 3}

/speech/say — std_msgs/String（smabo-web → smabo-app、読み上げテキスト） /speech/recognized — std_msgs/String（smabo-brain → smabo-web、認識テキスト）

{"data": "こんにちは"}

/speech/audio — audio_common_msgs/AudioData（smabo-app → smabo-brain、wake 後に録音した発話音声）

{"data": "<base64 エンコードした 16kHz モノラル WAV>"}

data は uint8[]（rosbridge では base64 文字列）。中身は自己記述的な WAV（ヘッダに フォーマット / サンプルレート / チャンネルを持つ）なので追加フィールドは不要です。

音声認識の流れ：smabo-app はウェイクワード検出だけを担当します。ウェイクワードを 検出すると発話を録音し（16kHz モノラル、無音が一定時間続いたら停止）、WAV を base64 化して /speech/audio（audio_common_msgs/AudioData）で smabo-brain に送ります。smabo-brain は受信音声を STT エンジン （既定 vosk、--stt-engine whisper で faster-whisper も選択可）で文字起こしし、結果を /speech/recognized として配信します（smabo-web で確認できます）。 ウェイクワード検出には Android の音声認識を用いるため、待ち受け中は error_speech_timeout が周期的に出ますが正常で、smabo-app 側がバックオフ付きで穏やかに待ち受けを再開します。

/odom — nav_msgs/Odometry（smabo-brain が /wheel_vel を積分して生成 → smabo-web / Nav2）

{
  "header": {"stamp": {"sec": 0, "nanosec": 0}, "frame_id": "odom"},
  "child_frame_id": "base_link",
  "pose":  {"pose":  {"position": {"x": 0.0, "y": 0.0, "z": 0.0},
                      "orientation": {"x": 0.0, "y": 0.0, "z": 0.0, "w": 1.0}},
            "covariance": ["…6×6 行優先 36 要素…"]},
  "twist": {"twist": {"linear":  {"x": 0.0, "y": 0.0, "z": 0.0},
                      "angular": {"x": 0.0, "y": 0.0, "z": 0.0}},
            "covariance": ["…6×6 行優先 36 要素…"]}
}

covariance（各 36 要素）は smabo-brain が encoder.covariance.* から付与します。

/scan — sensor_msgs/LaserScan（smabo-esp32 の LD06 → smabo-brain → Nav2）

{
  "header": {"stamp": {"sec": 0, "nanosec": 0}, "frame_id": "laser"},
  "angle_min": 0.0,
  "angle_max": 6.2657,
  "angle_increment": 0.01745,
  "time_increment": 0.0,
  "scan_time": 0.1,
  "range_min": 0.05,
  "range_max": 12.0,
  "ranges": ["…距離(m) の配列。0.0 は無反射…"],
  "intensities": []
}

/ping / /pong — std_msgs/String（疎通確認。web → esp32 が /ping、esp32 → web が /pong でエコー）

{"data": "<往復照合用トークン>"}

rosbridge モード（smabo-brain-ros）では、上記の中継・prefix 剥がしを rosbridge_server ＋ relay ノードが担います。各クライアントは publish の前に advertise、受信の前に subscribe が 必要です（詳細は smabo-brain-ros の README を参照）。

## コンポーネント概要#

### smabo-app#

smabo の「顔（目）」を表示し、スマートフォンの IMU / GPS / カメラをセンサとして提供します。 音声はウェイクワード検出と録音だけを担当し（STT は smabo-brain）、ウェイクワード後の録音音声を /speech/audio で送ります。WS / で smabo-brain に接続し、/app prefix でセンサを publish、/look_at・/expression・ /speech/say を受けて目や発話を制御します。

### smabo-web#

ブラウザ上の制御 UI（React / TypeScript）。Face / Sensors / Drive / Servo / Config / Log タブに加え、 ROS 2 連携時は Navigation / Motion Plan タブ（roslib + 3D ビューア）で Nav2 / MoveIt2 を操作します。 WS /ui で smabo-brain に接続（/web prefix）。config / mode は ESP32 へ REST 直通で設定します。

### smabo-brain#

全コンポーネントが接続する中継ハブ（aiohttp）。送信元 prefix を剥がして canonical 名で再配信し、 マイコンではできない上位処理（オドメトリ積分 /wheel_vel → /odom、カメラ映像の画像処理、 /speech/audio の音声認識（STT） → /speech/recognized など）を担います。STT エンジンは 既定 vosk、--stt-engine whisper で faster-whisper も選択できます（brain.stt、未導入なら無効）。 純ロジック（brain.odometry・brain.topics）は transport から分離されており、 smabo-brain-ros が import して再利用します。

### smabo-brain-ros#

smabo-brain の ROS 2 ラッパー兼 ROS 2 ランタイム。rosbridge_suite（WS ↔ ROS 2）＋ Nav2（ナビゲーション） ＋ MoveIt2（動作計画）＋ odom_node ＋ 画像処理（brain.vision 再利用）＋ 音声認識 （speech_recognizer_node：/speech/audio→STT→/speech/recognized、brain.stt 再利用）を提供します。 外部（web / app / esp32）は rosbridge 経由で ROS グラフに接続し、smabo-brain の純ロジックを再利用します。

カメラ映像は rosbridge をバイパスします。rosbridge は JSON over WebSocket のため、映像を /camera/image/compressed（base64 JSON）として通すとリアルタイム性が落ちます。そこで smabo-brain-ros は WebRTC 終端ノード（webrtc_camera_node、brain.webrtc_hub を再利用）を 持ち、smabo-app からの WebRTC 映像を終端してフレームを取り出し、ネイティブ ROS の sensor_msgs/Image（/camera/image_raw）として DDS に publish します。これを image_processor_node 等が購読するため、ROS グラフ内は高速なネイティブ転送になります。 WebRTC のシグナリング（/webrtc/*、小さい JSON）は rosbridge 経由で問題ありません。

### smabo-esp32（概要）#

ESP32 上の MicroPython ファームウェア。サーボ（PCA9685）・DC モータ（TB6612）・エンコーダ・ LD06 ライダを制御 / 取得します。WS /esp32 で smabo-brain に接続。詳細は §1 以降を参照してください。

## 画像処理（物体検出と追従）#

smabo-app のカメラ映像（WebRTC）を smabo-brain（および smabo-brain-ros）が受け取り、 capture_fps（/vision/config）の頻度でフレームを取り出して物体の画像内位置を算出し、 vision_msgs/Detection2DArray 互換で配信します。 その検出結果から、目（/look_at）・首サーボ（/servo/command）・走行（/cmd_vel）の 各 behavior が「対象を向く／追従する」動きを生成します。検出（知覚）と振る舞い（behavior）を 分離し、同じ検出結果を複数アクチュエータで再利用できる構成です。

純ロジック（検出・幾何変換・各 policy）は brain.vision に集約し、smabo-brain（WS）と smabo-brain-ros（ROS2）が import して再利用します（brain.odometry と同じ分離方針）。

### データフロー#

sequenceDiagram
    participant app as smabo-app
    participant brain as smabo-brain / brain-ros
    participant web as smabo-web
    participant esp32 as smabo-esp32

    web->>brain: /vision/config（mode/color/speak/behaviors/capture_fps …）
    app->>brain: カメラ映像（WebRTC）
    Note over brain: フレームを取り出し brain.vision で検出（aruco/color/face/qr）
    brain->>web: /vision/detections（Detection2DArray）・/vision/markers（String）
    Note over brain: 最大面積の検出 → 方向に変換 → 各 policy
    brain->>app: /look_at（目を向ける）
    brain->>esp32: /servo/command（首を向ける）
    brain->>esp32: /cmd_vel（mobile_robot 追従）
    brain->>app: /speech/say（AR/QR 文字列の発話・任意）
    brain->>web: カメラ映像中継（WebRTC、プレビュー ON 時のみ）

### 処理モード#

モード | 内容 | 文字列配信
off | 無効 | —
aruco | AR マーカー検出（位置＋ID）。辞書は aruco_dict（"ALL" で全辞書走査） | マーカー番号 → /vision/markers
color | 指定色の物体の中心（HSV しきい値）。色はカラーパレットの任意 RGB（color_rgb）または名前付きプリセット | —
face | 顔検出（OpenCV Haar） | —
qr | QR コード（位置＋内容） | 内容 → /vision/markers

speak=true のとき、aruco の番号 / qr の内容を /speech/say に流して smabo-app が発話します。 同じ文字列の連投は brain 側で抑制（変化時のみ送出）し、smabo-app 側にも 「同一文字列を連続受信したら無視する」設定を用意します。

### コンポーネントと配置#

役割 | smabo-brain（WS） | smabo-brain-ros（ROS2）
検出 | カメラ受信 → brain.vision → /vision/detections・/vision/markers を配信 | image_processor_node（CompressedImage → Detection2DArray ＋ String）
gaze policy | detections → /look_at | gaze_policy_node
neck policy | detections → /servo/command | neck_policy_node
drive policy | detections → /cmd_vel（mobile_robot 追従） | drive_policy_node
制御 | /vision/config を intercept | image_processor_node が subscribe

CV は重いので brain では別スレッド（executor）で実行して中継ループを止めません。処理は間引き（例 10 fps）。

### 制御メッセージ（/vision/config）#

smabo-web → smabo-brain（rosbridge モードでは relay 経由）。std_msgs/String の data に設定 JSON（文字列）を入れます。部分指定でよく、brain は現在値に deep-merge（target_joints / behaviors / drive はキー単位でマージ、スカラは置換）して保持します。更新後は brain が正規化済みスナップショットを全 UI に再配信し、新規接続 UI には接続直後に現在値を1通送って同期します。

{
  "enabled": true,
  "mode": "color",
  "color": "red",
  "color_rgb": "#1e90ff",
  "color_hue_tol": 12,
  "color_s_min": 70,
  "color_v_min": 60,
  "min_area_frac": 0.0008,
  "aruco_dict": "DICT_4X4_50",
  "speak": false,
  "hfov_deg": 60.0,
  "target_marker_id": null,
  "target_joints": {"pan": "head_pan", "gain": 1.0},
  "behaviors": {"look_at": true, "servo": false, "drive": false},
  "drive": {"target_area_frac": 0.10, "k_ang": 1.5, "k_lin": 2.0,
            "max_ang": 1.0, "max_lin": 0.20, "deadzone": 0.02}
}

キー | 説明
enabled / mode | 有効無効 / 検出モード（off / aruco / color / face / qr）
color | 色モードの名前付きプリセット（red / orange / … / purple）。color_rgb が未設定のときの既定
color_rgb | 色モードの任意の対象色（カラーパレットから取得した #RRGGBB または [r,g,b]）。設定時は color より優先
color_hue_tol | color_rgb の色相許容幅（OpenCV H 0–179 の±半幅。大きいほど広く拾う）
color_s_min / color_v_min | 色モードの彩度・明度の下限（0–255）。下げるほど淡い/暗い色も拾う（誤検出増）
min_area_frac | 検出の最小サイズ（フレーム面積に対する割合）。これ未満の検出を全モードで除外（微小ノイズ・ALL の誤検出抑制）
aruco_dict | AR モードの辞書（例 DICT_4X4_50）。印刷したマーカーと一致が必要。"ALL" で代表的な全辞書を走査（少し重く・誤検出増）。検出器はキャッシュ
speak | 検出文字列を /speech/say に流すか
hfov_deg | カメラ水平画角（pixel → 角度の変換に使用）
target_marker_id | 追従を優先する AR ID（null＝最大面積）
target_joints | 首 policy が動かす関節・符号・ゲイン（任意設定）
behaviors | look_at / servo / drive の個別有効化
drive | 追従の目標サイズ率・ゲイン・上限速度

### 起動時初期値とメッセージ型の選定#

起動時初期値：smabo-brain は起動時に画像処理設定の初期値を読み込めます。

- --vision-config <path.json>（または環境変数 SMABO_VISION_CONFIG）で JSON ファイルを指定。中身は上の /vision/config の data と同形（部分指定可、欠けたキーは組み込み既定で補完）。
- 未指定なら組み込み既定（mode=off・検出無効・behaviors.look_at=true・首は head_pan のみ・tilt なし）で起動。
- 起動後は /vision/config で実行中に部分上書き。「起動時初期値＋実行時上書き」が brain 単体（WS）でも smabo-brain-ros（ROS）でも成立します。

型の選定（なぜ String + JSON か）：検出結果のようなデータプレーンは標準型（vision_msgs/Detection2DArray・geometry_msgs/PoseStamped）で相互運用性を確保する一方、設定のようなコントロールプレーンは std_msgs/String＋JSON にしています。設定は mode/color/target_joints/behaviors/drive と異種・入れ子・将来追加が多く、これに合う標準 ROS メッセージ型が無いこと、1トピックに集約でき型変更なしでフィールド追加できること、rosbridge/Web から扱いやすいことが理由です。

ROS 的には設定はノードパラメータが本来の場所なので、smabo-brain-ros 側では image_processor_node の ROS 2 パラメータとしても公開し、ros2 param で操作できるようにします（Web↔brain は String/JSON、ROS 側はパラメータ、の二段構え）。両者の初期値・上書きは brain.vision.merge_config（純ロジック）で同一に適用します。

### メッセージ定義（vision）#

/vision/detections — vision_msgs/Detection2DArray（smabo-brain → web。smabo-brain-ros は ROS2 型）

{
  "header": {"stamp": {"sec": 0, "nanosec": 0}, "frame_id": "camera"},
  "source_img_width": 640, "source_img_height": 480,
  "detections": [{
    "header": {"stamp": {"sec": 0, "nanosec": 0}, "frame_id": "camera"},
    "bbox": {"center": {"position": {"x": 320.0, "y": 180.0}, "theta": 0.0},
             "size_x": 96.0, "size_y": 96.0},
    "results": [{"hypothesis": {"class_id": "face", "score": 0.92}}]
  }]
}

class_id は AR=マーカー番号、color=色名、face="face"、qr=内容。center.position は画素座標。 source_img_width/height は標準外の補助フィールド（消費側が画素→正規化する手掛かり）。

/vision/markers — std_msgs/String（AR 番号 / QR 内容。複数はカンマ区切り）

{"data": "3,7"}

### policy（pixel→方向→各指令）#

最大面積（または指定 AR ID）の検出を対象に、画素位置と画角からロボット座標系の方向ベクトル (x=前, y=左, z=上) を求め（bbox_to_direction）、各 behavior に変換します。

- gaze → /look_at（PoseStamped）：position に方向ベクトルをそのまま入れる
- neck → /servo/command：pan = atan2(y, x)、tilt = atan2(z, hypot(x, y))（config の関節・符号・ゲイン）
- drive → /cmd_vel：angular.z = -k · u_n（対象を水平中央へ）、linear.x = k · (目標面積率 − 現面積率)（bbox の見かけサイズを距離の代理に前後）。正面でないときは前進抑制、対象ロスト時は停止。

手動操作との競合：vision 有効時のみ各 policy が出力します。gaze は smabo-web の Face タブの手動 GazePad と同じ /look_at（app の follow モード）を共有するため、vision の gaze が有効な間は Face タブの GazePad を無効化して排他にします（「Vision が gaze を制御中」と表示）。neck / drive も同様に vision 有効時はその出力が優先されます。

以下 §1〜§8 は smabo-esp32（ファームウェア）の詳細です。 ESP32 は中継サーバ smabo-brain へ WebSocket クライアントとして接続し （ws://<brain-host>:<port>/esp32）、アクチュエータ制御とセンサ取得を担います。 制御指令は smabo-web → smabo-brain 経由で届き、ホイール速度等は smabo-brain へ送ります。

## 1. モジュール構成#

smabo-esp32/
├── main.py              # 起動エントリ・asyncio イベントループ
├── config.py            # 永続設定（RAM + config.json、デバウンス保存）・DEFAULTS
├── wifi_manager.py      # WiFi 接続・自動再接続
├── ws_client.py         # RFC 6455 WebSocket クライアント（smabo-brain へ接続・自動再接続、外部ライブラリ不要）
├── robot.py             # オーケストレータ（rosbridge プロトコル・モード管理）
├── pca9685.py           # PCA9685 PWM ドライバ（サーボ用 I2C）
├── servo_controller.py  # JointGroup（全サーボ共通）
├── random_motion.py     # グループ単位のランダム動作（タイミンググループ管理）
├── dc_motors.py         # TB6612 差動駆動（cmd_vel 受信・デッドマン停止）
├── encoder.py           # GPIO 割り込みによるエンコーダカウント
├── wheel_publisher.py   # エンコーダ → ホイール速度（/wheel_vel）送信。オドメトリ積分は smabo-brain 側
├── config.json          # 実機の差分設定（DEFAULTS へ deep-merge。WiFi / brain 接続先 等。git 管理外）
└── configs/             # ボード別 config.json テンプレート（後述 §8）
    ├── config.esp32-classic.json     # ESP32（無印）DevKit 38pin
    ├── config.esp32s3-devkitc1.json  # ESP32-S3-DevKitC-1 / DevKitM-1 系
    └── config.xiao-esp32s3.json      # Seeed XIAO ESP32-S3

config.json は config.py の DEFAULTS に対する差分のみを保持します（起動時に deep-merge）。 ボードを変えるときは configs/ の該当ファイルをデバイス直下に config.json としてコピーします。
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

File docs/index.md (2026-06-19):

<!--
以下は、md -> html 生成の際の指示（html生成時に直接出力する箇所ではない。以降、コメントアウトしてある箇所は、html生成時の注意事項が記載してあるものとする）

- markdownにて記載した文章は、誤字・脱字を除き、一切省略せずに、全く同じ文章でhtmlに反映すること（改行のタイミングなども含む）
    - 追記、修正した方がいい文章があった場合は、必ずユーザーに確認した上で、了承を得られた場合のみmarkdown, htmlともに修正すること
- 誤字、脱字があった場合は、markdown,html両方とも修正すること
- 表記揺れがあった場合は、どちらに統一するかユーザー側に確認したのちに、markdown, htmlともに、指定された表記に統一されるように修正すること
- 処理内容などに言及する部分に関しては、間違いがないか（コードが存在する場合は）コードの内容と照らし合わせて確認すること。その際、不整合があった場合は、ユーザー側に確認した上で了承が得られたら、markdown,htmlともに修正すること
- その他不正確な内容が含まれている場合は、ユーザー側に確認した上で了承が得られたら、markdown,htmlともに修正すること
-->

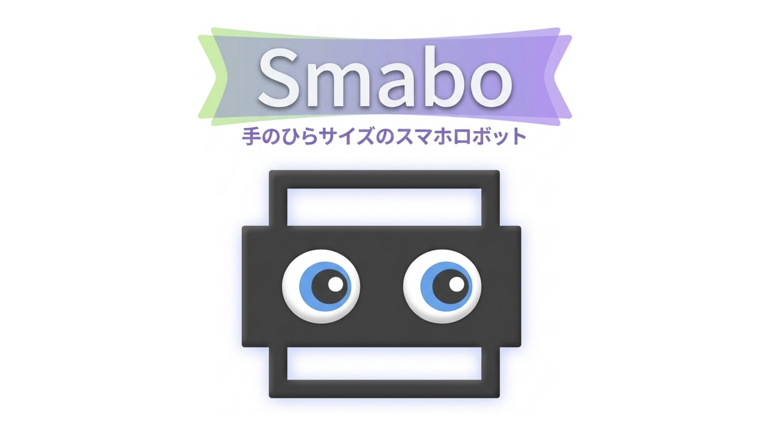
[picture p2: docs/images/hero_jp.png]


工具不要で組み立て可能な<br>スマホ搭載ロボットです

# できること

初学者向けの<br>
様々な機能がそろっています

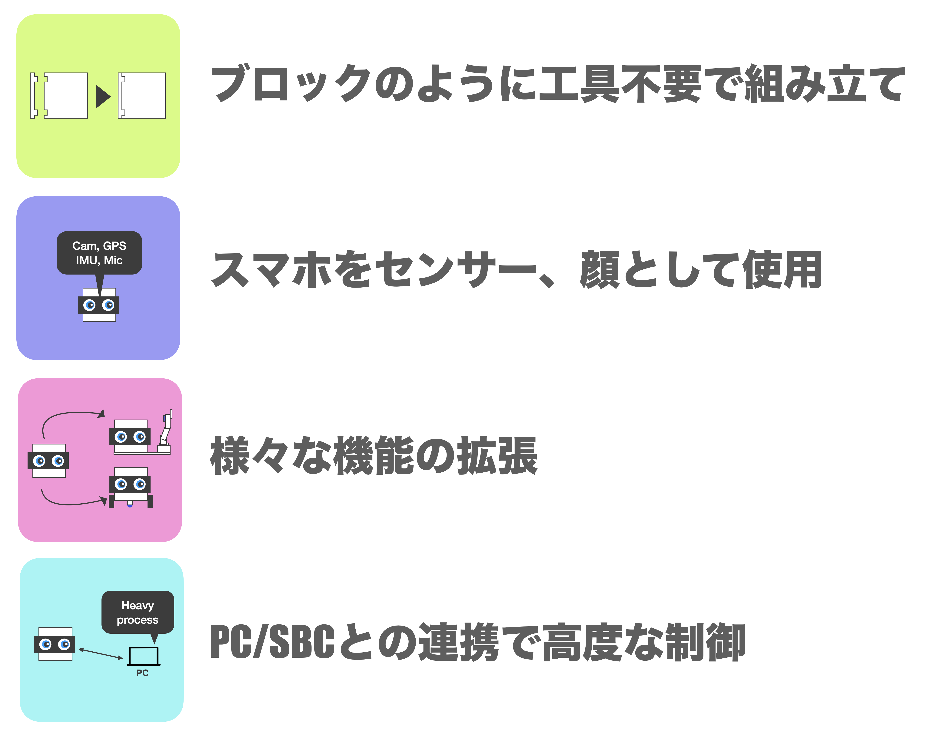
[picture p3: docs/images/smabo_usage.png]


# つくりかた

ロードマップを使って<br>smaboを少しずつ作っていきましょう
<br>※ 各ブロックを選択すると、詳細ページにジャンプできます

<!--
下図の構成を参考にインタラクティブな図をここにおいてください（下記のsvgファイルそのものはhtmlには出力しない）。

具体的には
- 対象の記事にリンクがつながっている四角にマウスをホバーすると「この記事の内容を実現するまでにどの記事を読んでおく必要があるか」「この記事の後につながる記事はどれなのか」がハイライトされる
- 四角内をクリックすると、その記事のリンクへ飛ぶ
-->



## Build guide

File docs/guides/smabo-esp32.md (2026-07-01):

<!--
以下は、md -> html 生成の際の指示（html生成時に直接出力する箇所ではない。以降、コメントアウトしてある箇所は、html生成時の注意事項が記載してあるものとする）

- markdownにて記載した文章は、誤字・脱字を除き、一切省略せずに、全く同じ文章でhtmlに反映すること（改行のタイミングなども含む）
    - 追記、修正した方がいい文章があった場合は、必ずユーザーに確認した上で、了承を得られた場合のみmarkdown, htmlともに修正すること
- 誤字、脱字があった場合は、markdown,html両方とも修正すること
- 表記揺れがあった場合は、どちらに統一するかユーザー側に確認したのちに、markdown, htmlともに、指定された表記に統一されるように修正すること
- 処理内容などに言及する部分に関しては、間違いがないか（コードが存在する場合は）コードの内容と照らし合わせて確認すること。その際、不整合があった場合は、ユーザー側に確認した上で了承が得られたら、markdown,htmlともに修正すること
- その他不正確な内容が含まれている場合は、ユーザー側に確認した上で了承が得られたら、markdown,htmlともに修正すること
-->

# 目次 <!-- omit in toc -->

- [ロードマップ](#ロードマップ)
- [概要](#概要)
- [必要パーツ](#必要パーツ)
- [smabo-esp32のセットアップ](#smabo-esp32のセットアップ)
  - [Thonny（書き込みソフト）のインストール](#thonny書き込みソフトのインストール)
    - [ソースコードの書き込み](#ソースコードの書き込み)
    - [設定ファイルの書き込み](#設定ファイルの書き込み)
- [パーツの印刷](#パーツの印刷)
- [ブレッドボードについて](#ブレッドボードについて)
- [組み立て手順](#組み立て手順)
- [配線](#配線)
- [動作手順](#動作手順)
  - [起動手順](#起動手順)
- [次回](#次回)

# ロードマップ

本ページは、以下ロードマップ「smabo-esp32」のガイドページです。

また、本ページは「[ベースパーツの作成](./base.md)」のガイドを実施している前提で話を進めます。

<!--
htmlに変換する際は、以下のsvgファイルの代わりに、roadmap.htmlに記載してあるロードマップを添付すること。ただし、本ページのノードをハイライトした状態にすること。また、roadmap.htmlに記載のロードマップの0.5倍のサイズとすること。
-->



# 概要

本ページでは「smabo-esp32」のセットアップ手順について解説します。

smabo-esp32は
- esp32に繋いだセンサやアクチュエータの制御

の役割を担います。

<!-- 以下の、smabo_sysytem_architecture.drawio.svgの代わりに、sysmap.jsをもとに作成したアーキテクチャ図を配置する。-->
<!-- 以下例のように記述するので、ハイライトするノードと矢印、およびラベルに記述する内容を確認し、アーキテクチャ図を作成してください -->
<!-- 例）コンポーネント1 -[websocket]-> コンポーネント2：データ種類1, データ種類2 -->
<!-- 上記の場合、-->
<!-- 1. コンポーネント1、コンポーネント2をハイライト>
<!-- 2. コンポーネント1 -> コンポーネント2方向の、websocketにあたる矢印をハイライト-->
<!-- 3. 矢印には、「データ種類1、データ種類2」とラベルを記述。ここで、読点ごとに改行すること（読点はラベルには含まない）>
<!-- 4. ラベルの行数が増えると、ラベルがノードや矢印通しで重なる可能性があるので、重なっていないことを確認すること-->

<!-- 今回の、具体的な構成は以下になります。 -->
<!-- セットアップだけなので、smabo-esp32をハイライトするだけ -->



# 必要パーツ

本機能の実装に必要なパーツを以下に記載します。

| 部品名 | 商品URL | 備考 |
| --- | --- | --- |
| ESP32-DevKitC | [link](https://www.amazon.co.jp/ESP32-DevKitC-Bluetooth-機能マイクロコントローラー-TYPE-C-デュアルコアボード/dp/B0GTY64KDC/ref=asc_df_B0GTY64KDC?mcid=350a4550c70e3d30953041512ffe110a&tag=jpgo-22&linkCode=df0&hvadid=792079627413&hvpos=&hvnetw=g&hvrand=17366440597157412973&hvpone=&hvptwo=&hvqmt=&hvdev=c&hvdvcmdl=&hvlocint=&hvlocphy=9199153&hvtargid=pla-2484301629565&hvocijid=17366440597157412973-B0GTY64KDC-&hvexpln=0&th=1)| 互換品でも可 |
| ブレッドボード（SAD101）<br> | [link](https://www.amazon.co.jp/サンハヤト-ニューブレッドボード-SAD-101/dp/B00DSKCS68?th=1)| 一般的なブレッドボードは5穴ですが、こちらは6穴になっています。<br>6穴でないとESP32のサイズ的に横幅が足りないので注意してください |
| ジャンプワイヤー | [link](https://www.amazon.co.jp/ELEGOO-120pcs%E5%A4%9A%E8%89%B2%E3%83%87%E3%83%A5%E3%83%9D%E3%83%B3%E3%83%AF%E3%82%A4%E3%83%A4%E3%83%BC%E3%80%81arduino%E7%94%A8%E3%83%AF%E3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) | - |
|電池ボックス（単3×4本、電池スナップ対応）|[link](https://www.amazon.co.jp/dp/B011IJQ4DI?ref_=ppx_hzsearch_conn_dt_b_fed_asin_title_3)| 電池スナップ対応の方が、取り回しが良いのでお勧めです。 |
|電池スナップ（電池ボックス用）|[link](https://www.monotaro.com/p/6866/1105/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)| コネクタピン付きの方が、ブレッドボードに差しやすくて、抜けにくいのでお勧めです。 |
| 充電式単三電池 × 4 | [link](https://www.amazon.co.jp/Amazon%E3%83%99%E3%83%BC%E3%82%B7%E3%83%83%E3%82%AF-AmazonBasics-HR-3UTG-AMZN-%E5%85%85%E9%9B%BB%E5%BC%8F%E3%83%8B%E3%83%83%E3%82%B1%E3%83%A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) | 充電式の方がおすすめです。 |
| 電池充電器 | [link](https://www.amazon.co.jp/%E3%80%90Amazon-co-jp%E9%99%90%E5%AE%9A%E3%80%91%E3%83%91%E3%83%8A%E3%82%BD%E3%83%8B%E3%83%83%E3%82%AF-%E6%80%A5%E9%80%9F%E5%85%85%E9%9B%BB%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) | - |
| サーボモータドライバ PCA9685 | [link](https://www.amazon.co.jp/HiLetgo-PCA9685-16%E3%83%81%E3%83%A3%E3%83%B3%E3%83%8D%E3%83%AB-12-%E3%83%93%E3%83%83%E3%83%88-Arduino%E3%81%AB%E5%AF%BE%E5%BF%9C/dp/B01D1D0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) | 互換品でも可<br><br>「ハンド」「首振り」「ロボットアーム」のページの内容を実装する際に必要です。<br>これらの内容を実施しない場合は不要 |
|ミニブレッドボード|[link](https://www.amazon.co.jp/Rasbee-SYB-170-%E3%83%9F%E3%83%8B%E3%83%96%E3%83%AC%E3%83%83%E3%83%89%E3%83%9C%E3%83%BC%E3%83%89-%E3%83%9B%E3%83%AF%E3%82%A4%E3%83%881%E5%80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)|裏面が粘着テープになっているもの|
| TB6612FNG搭載 デュアルモータードライバ | [link](https://www.amazon.co.jp/TB6612FNG%E6%90%AD%E8%BC%89-%E3%83%87%E3%83%A5%E3%82%A2%E3%83%AB%E3%83%A2%E3%83%BC%E3%82%BF%E3%83%BC%E3%83%89%E3%83%A9%E3%82%A4%E3%83%90-%E3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) | 互換品でも可（ただし、ピンヘッダ付きでないものは自分ではんだ付けする必要があります）<br><br>「移動ロボット」「エンコーダ付き移動ロボット」のページの内容を実装する際に必要です。<br>これらの内容を実施しない場合は不要 |

# smabo-esp32のセットアップ

## Thonny（書き込みソフト）のインストール

以下サイトから、PCのOSにあったThonnyのインストーラーのDL、インストールを行います。

https://thonny.org/

<br>

インストールが完了したら、Thonnyを起動してください。

### ソースコードの書き込み

ESP32とパソコンをUSBケーブルで接続した状態で、右下のボタンをクリックし「MicroPython(ESP32)」を選択します。

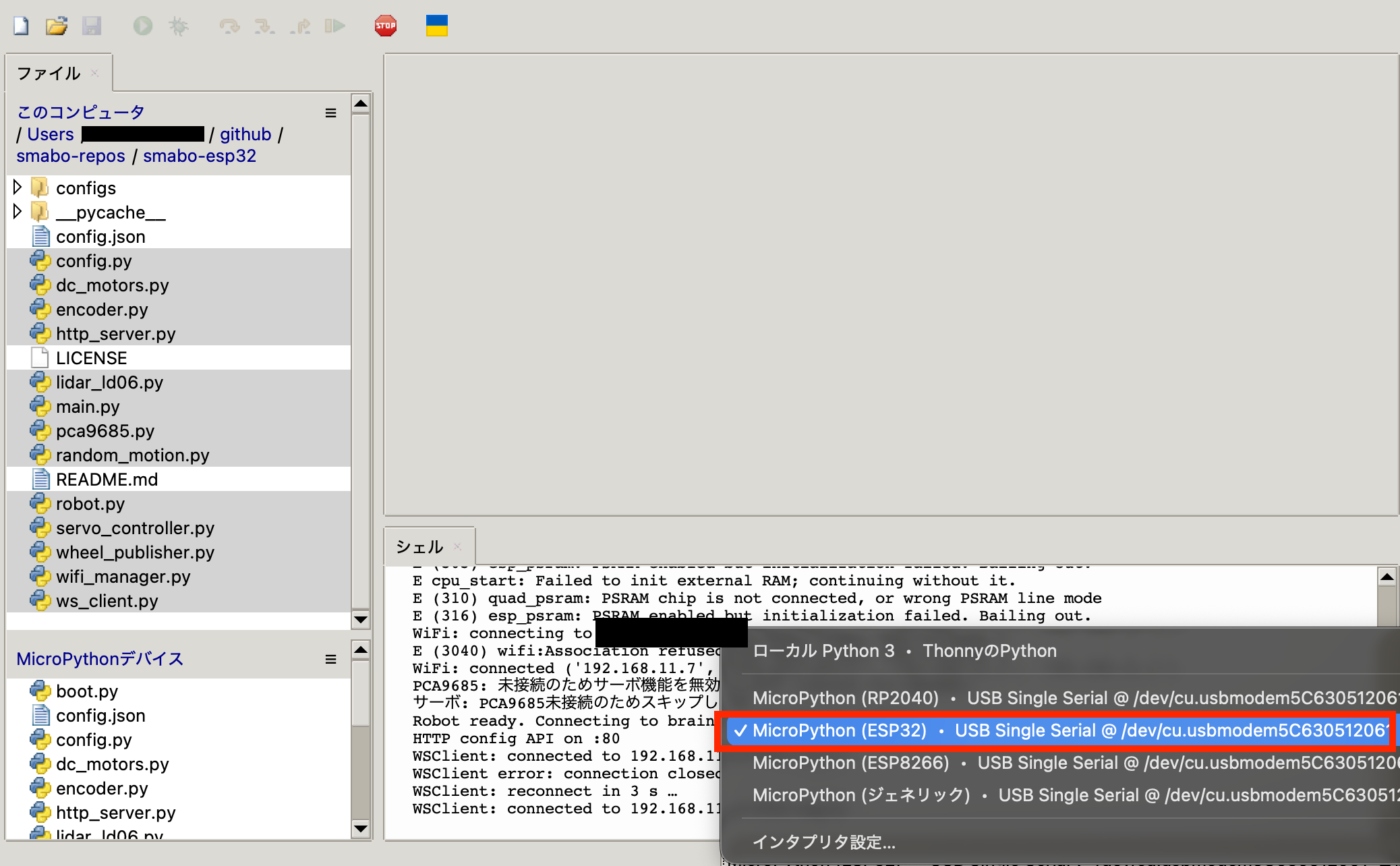
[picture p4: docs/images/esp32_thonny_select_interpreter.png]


<br>

その後、「smabo-esp32」内のpythonファイルを全て選択した状態で右クリックし、「/にアップロード」を選択すると、esp32に書き込まれます。

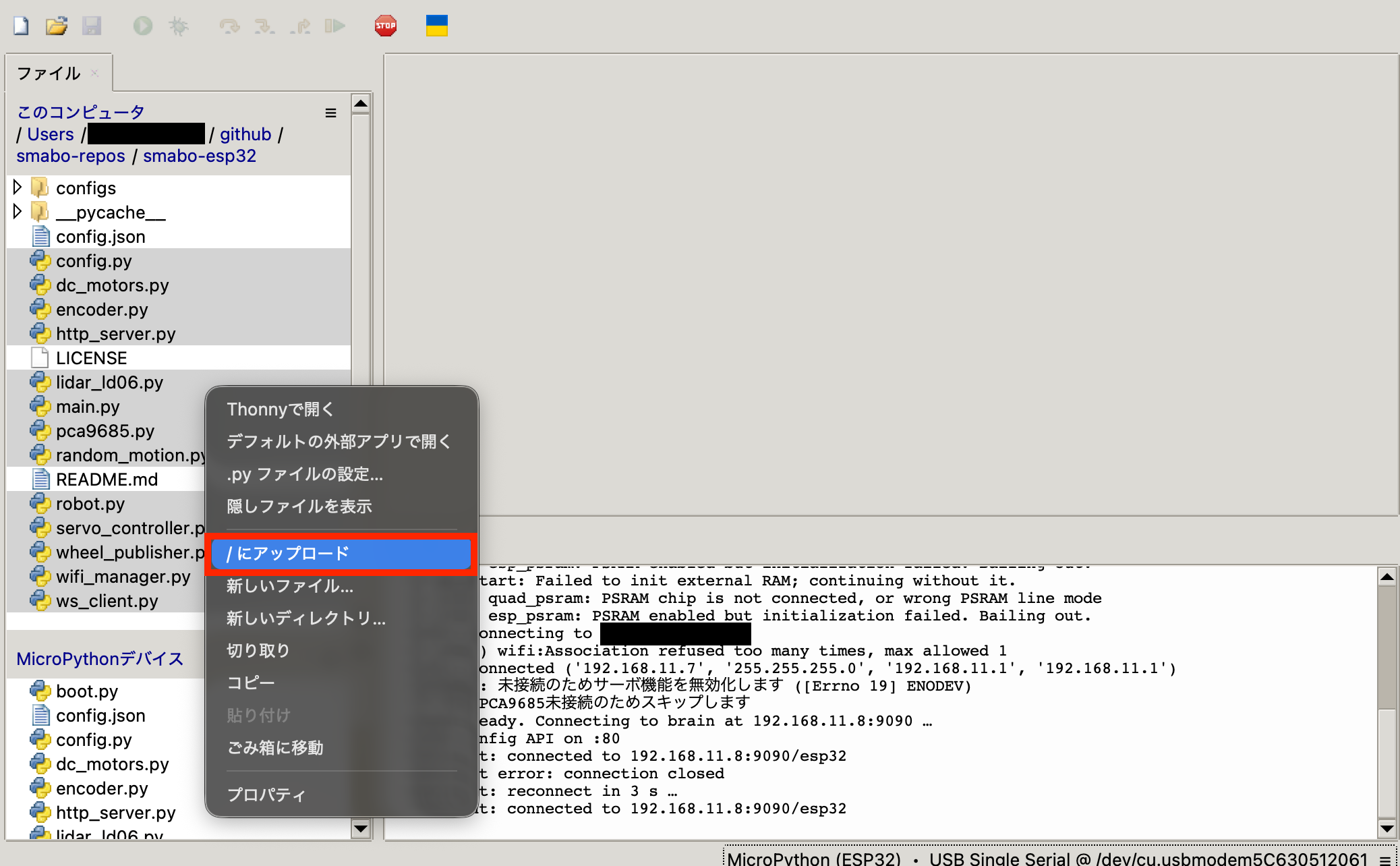
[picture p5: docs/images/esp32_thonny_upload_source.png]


### 設定ファイルの書き込み

次に、設定ファイルを書き込みます。

configディレクトリからお手持ちのesp32の種類にあったjsonファイルを選択し、「config.json」という名前でコピーを作成します。

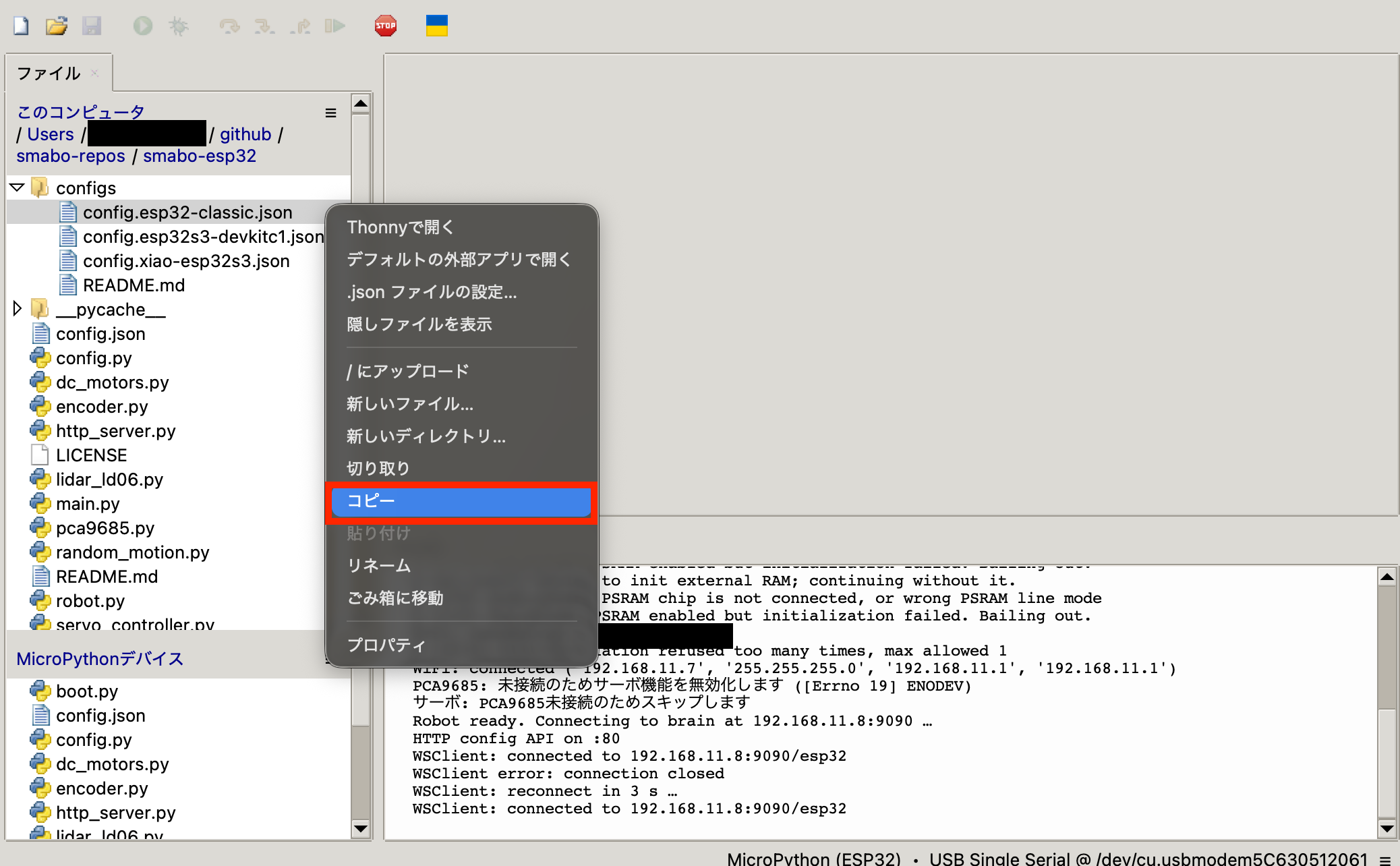
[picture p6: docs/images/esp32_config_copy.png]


<br>

以下項目を、環境に応じて記載してください。
- `wifi/ssid`：接続ネットワークのSSID
- `wifi/password`：接続ネットワークのpassword

!!! note 接続先WiFiの周波数について

    WiFiの周波数には2.4GHzと、5GHzの2種類がありますが、
    - esp32は、2.4GHzにしか対応していない
    
    ため注意してください。
    
    <br>

    一般に、
    - Buffalo-F-ooooのようにSSIDに「G」がついている場合は、2.4GHz
    - Buffalo-A-ooooのようにSSIDに「A」がついている場合は、5GHz

    となるため、ここで指定するSSIDは「G」がついている方にしてください。

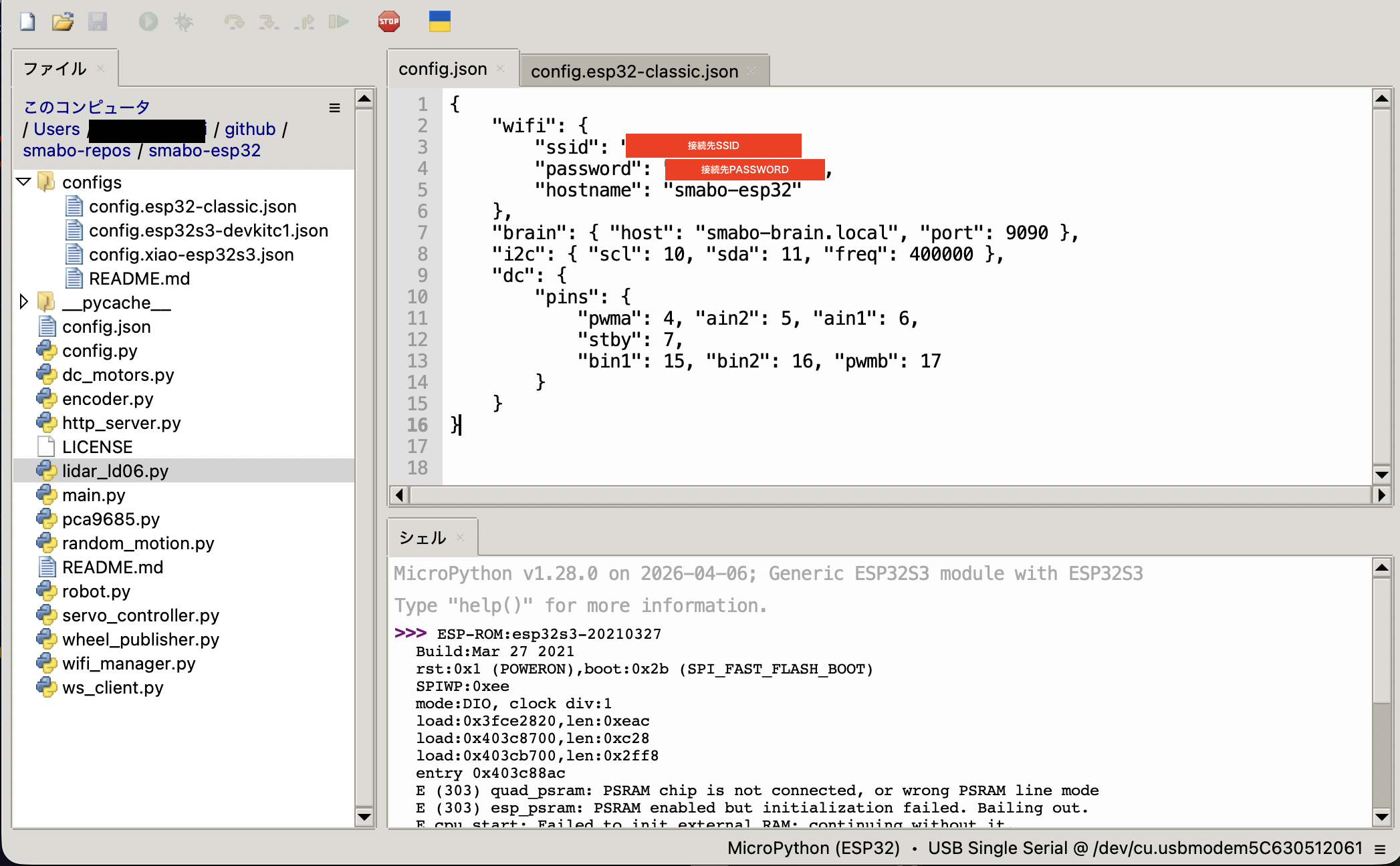
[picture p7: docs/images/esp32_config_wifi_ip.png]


<br>

設定の記入が完了したら、ソースコードの時と同様に、config.jsonをesp32へ書き込みます。

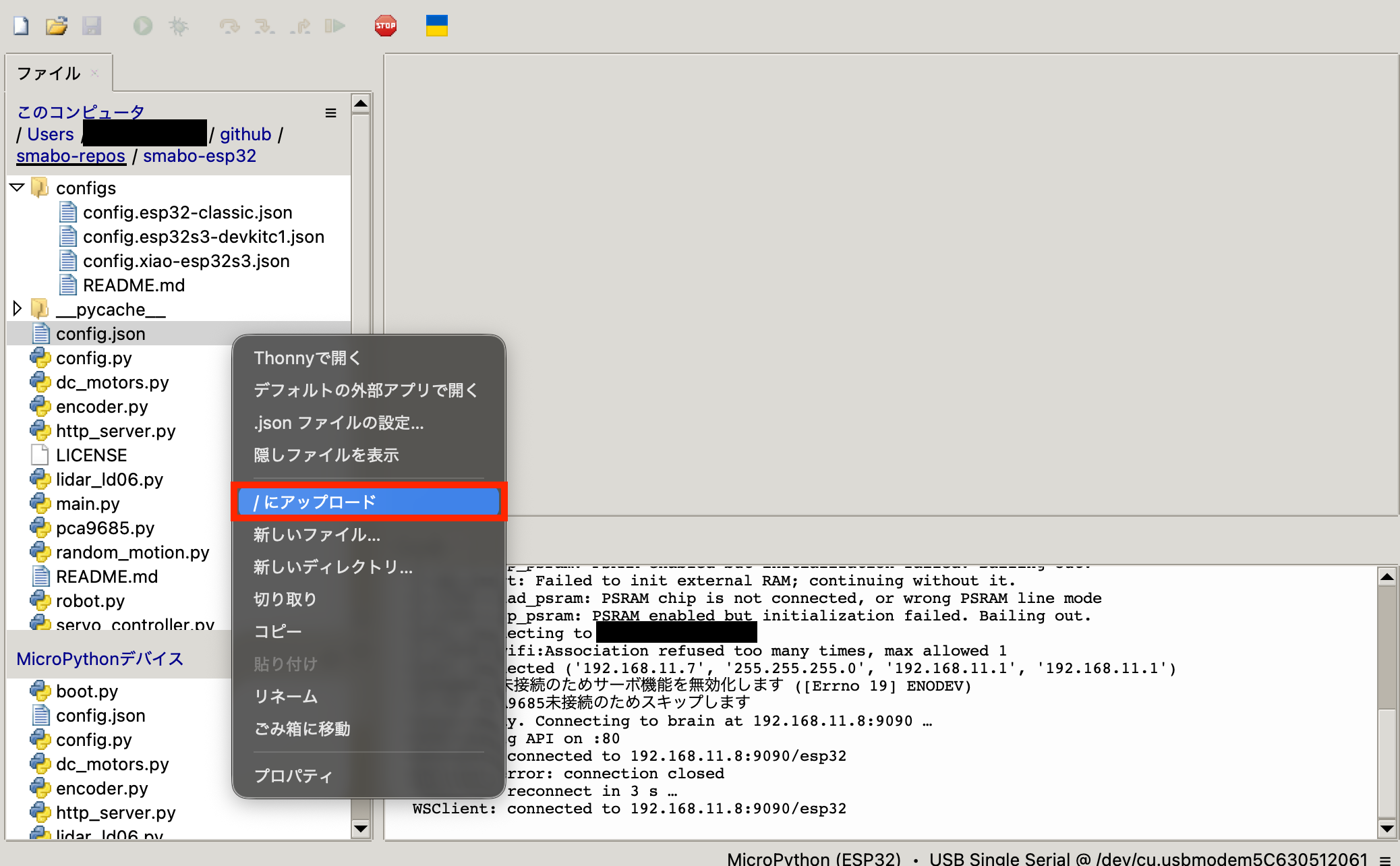
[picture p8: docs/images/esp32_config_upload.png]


# パーツの印刷

今回、新たに追加されるパーツを3Dプリンタで印刷します。

!!! note
    3Dプリンタは機種によって「印刷する際に使用するソフト」が異なるため、ここでは具体的な設定手順ではなく、ポイントのみを記載します。

以下のパーツを図の向きに設定して、印刷してください。

!!! note  印刷の際の注意点
    - パーツのつけ外しの際に、根本から折れにくくするため、凸部は横向きにして印刷
    - サポート材は必ずONにした状態で印刷

- smabo-hardware/stl/base/bread_board_stopper_bottom_l.stl
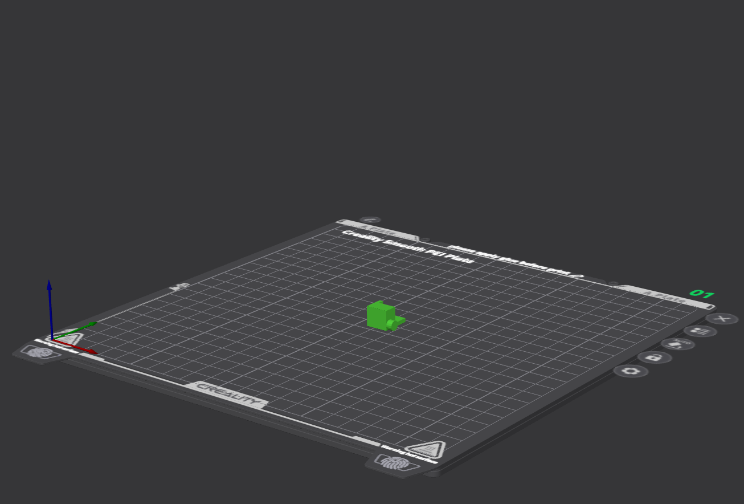
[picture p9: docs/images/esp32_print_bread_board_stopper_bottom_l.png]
    

<br>

- smabo-hardware/stl/base/bread_board_stopper_bottom_r.stl
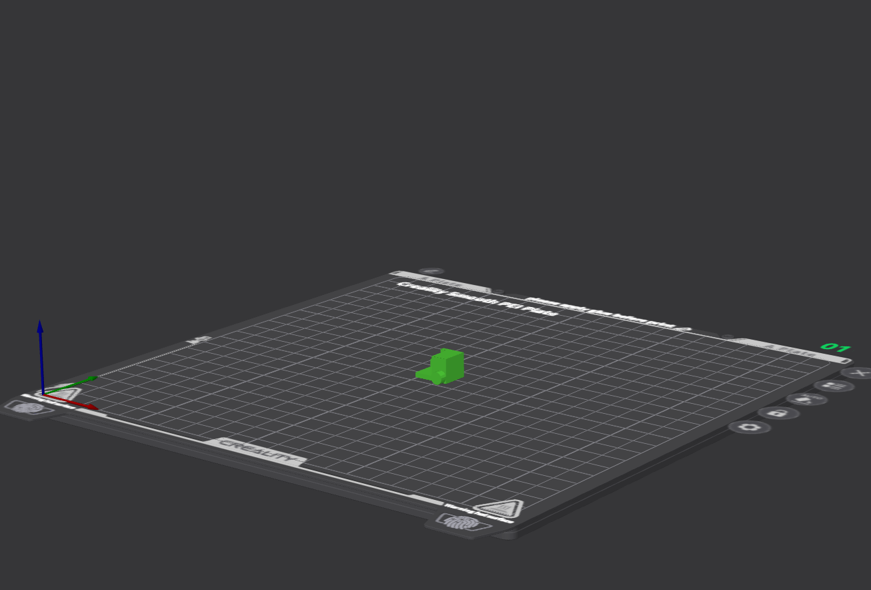
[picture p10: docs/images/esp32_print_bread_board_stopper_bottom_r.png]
    

<br>

- smabo-hardware/stl/base/bread_board_stopper.stl
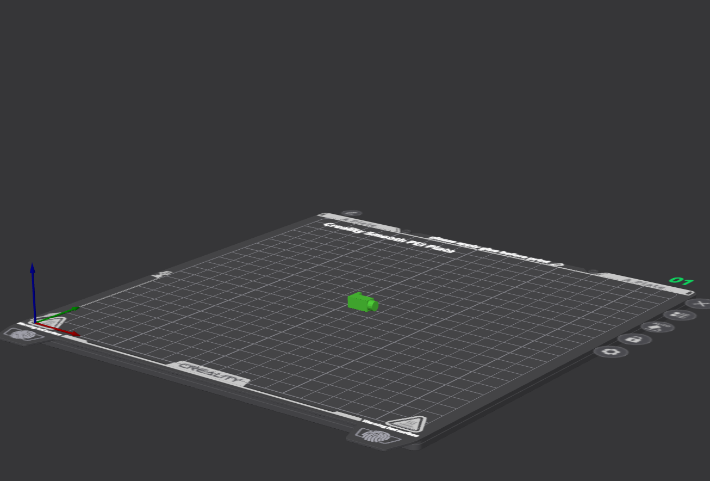
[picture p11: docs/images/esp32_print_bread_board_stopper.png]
    

<br>

- smabo-hardware/stl/base/mini_bread_boad_stand.stl
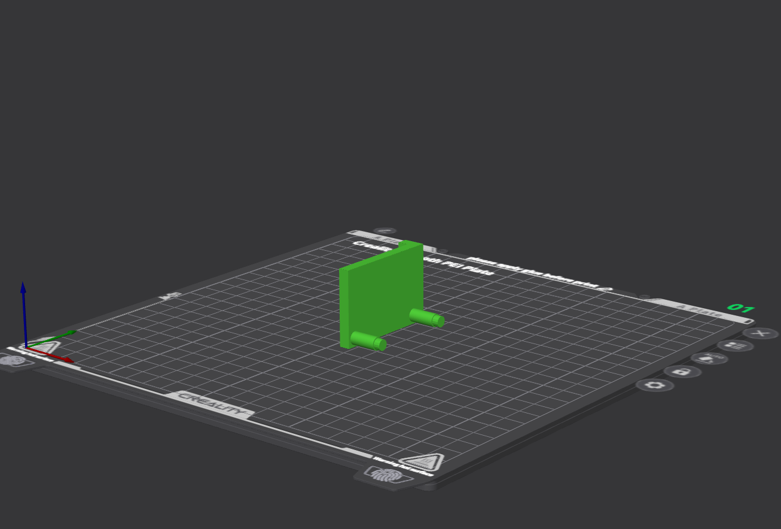
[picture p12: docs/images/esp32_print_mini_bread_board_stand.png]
    

<br>

- smabo-hardware/stl/base/pca9685_stopper_l.stl
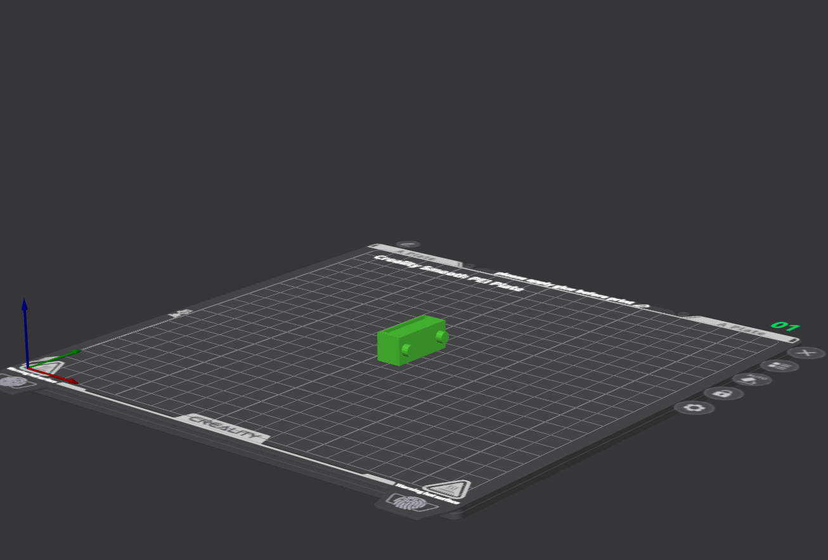
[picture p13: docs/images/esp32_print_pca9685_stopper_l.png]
    

<br>

- smabo-hardware/stl/base/pca9685_stopper_r_bottom.stl
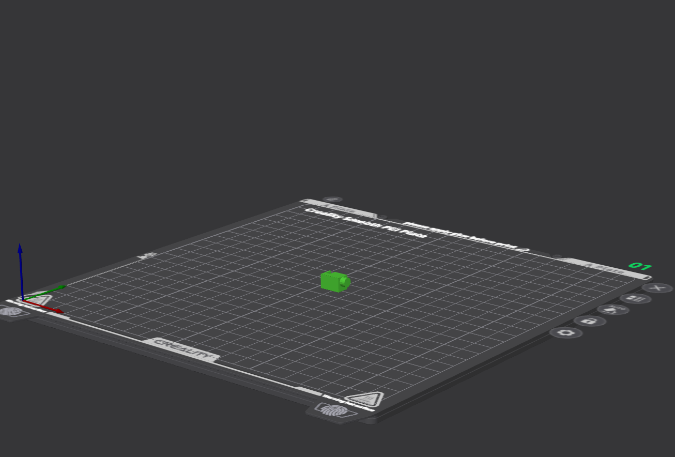
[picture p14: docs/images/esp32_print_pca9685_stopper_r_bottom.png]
    

<br>

- smabo-hardware/stl/base/pca9685_stopper_r_top.stl
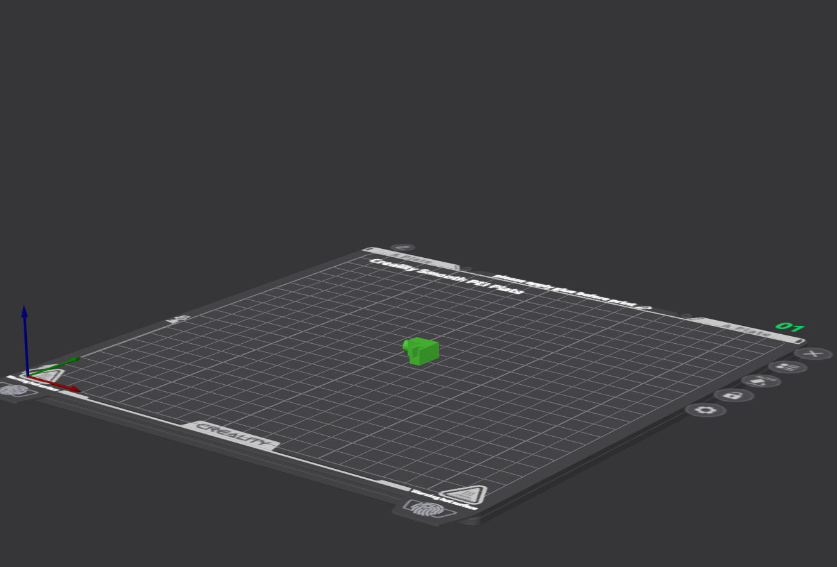
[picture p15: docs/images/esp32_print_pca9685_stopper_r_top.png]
    

<br>

- 【オプション】smabo-hardware/stl/base/in_base_plate_wire_hole.stl
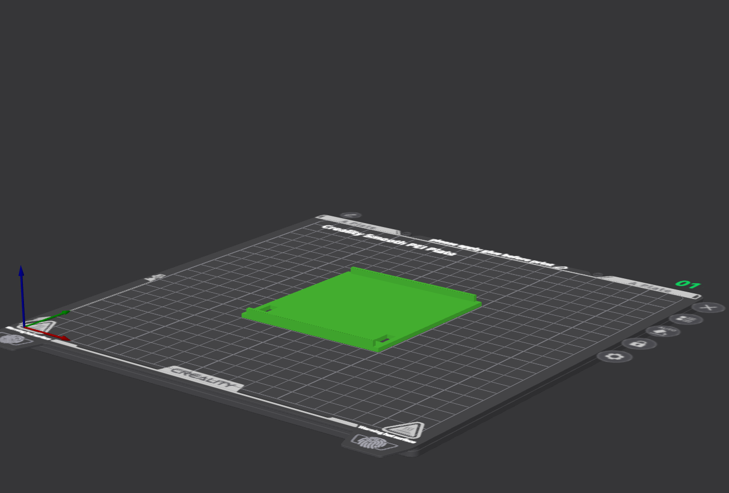
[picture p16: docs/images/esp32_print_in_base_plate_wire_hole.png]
    
    - 本パーツは、「smabo内の仕切り」として使用できます。
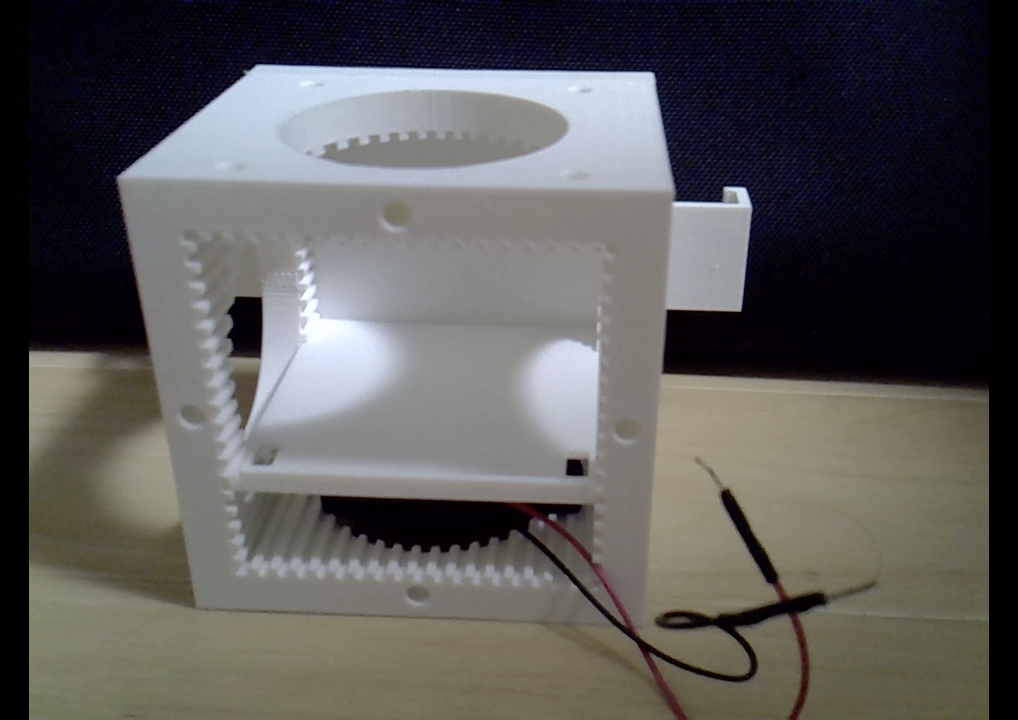
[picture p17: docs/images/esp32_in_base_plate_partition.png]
    

# ブレッドボードについて

SAD101は購入時の状態では、＋極の真ん中にジャンプワイヤーが挿さっています。

smaboでは、
- +極の「**右側**」を6V電源（乾電池×4）用
- +極の「**左側**」を5V電源（ESP32からの出力）用

として使用します。

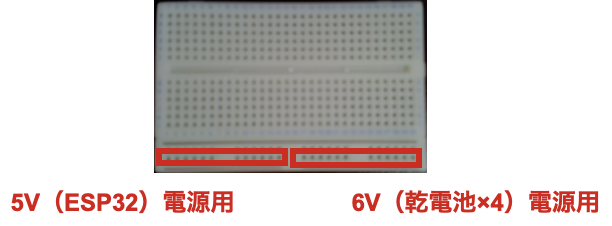
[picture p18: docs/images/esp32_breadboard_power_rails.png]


<br>

そのため、真ん中のジャンプワイヤーは外してください。

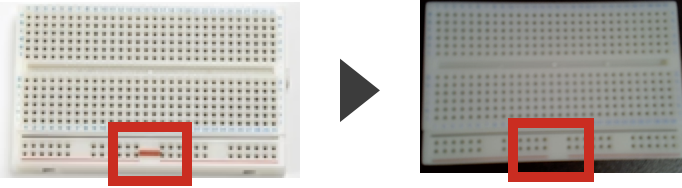
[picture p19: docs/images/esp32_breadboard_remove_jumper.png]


!!! note ブレッドボードの中身について
    ブレッドボードの裏面を見てみると、金属の棒が固定してあることがわかります。

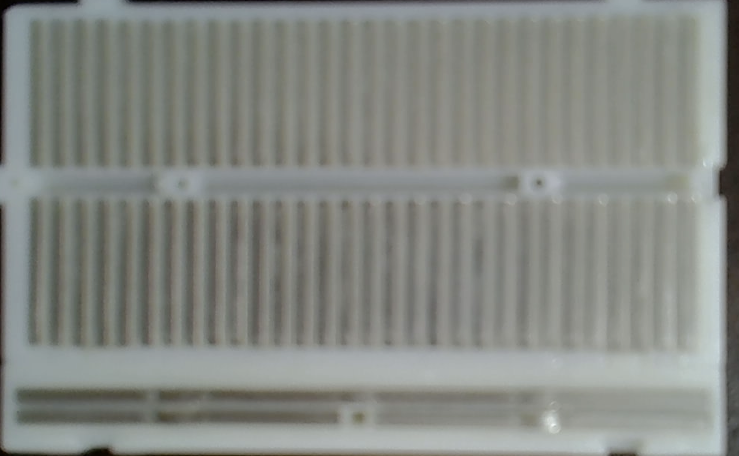
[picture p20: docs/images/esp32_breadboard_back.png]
    

    <br>
    <br>

    そのため、「同じ棒と繋がっている穴」に、複数のジャンプワイヤーを刺した場合、それらは回路的に繋がることになります。

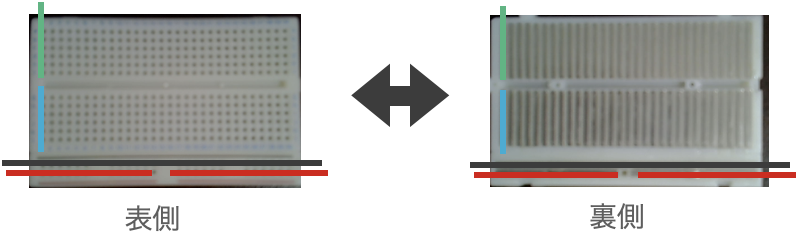
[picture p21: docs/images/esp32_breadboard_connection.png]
    

    <br>

    特に、SAD101の場合
    - +極のみ真ん中で途切れていて左右に分かれている

    ため、ジャンプワイヤーは、「+極を1直線に繋ぐために付いていた」ということになります。

    ※ 今回は、先述の通り左右で違う電源を使用するため、外しています

# 組み立て手順

以下動画のように、必要パーツを組み立てます。

※ 動画には、前回までに印刷したパーツも含まれます

<!--ここに、docs/assembly_movie/base_bread_board.htmlの組み立て動画を置いてください-->

!!! note 組み立ての際のポイント
    各パーツを使って、ブレッドボード、PCA9685、ミニブレッドボードを取り付けてください。

    なお、特に以下の点には注意してください。
    - ESP32はブレッドボードの左端に差し込んでください
    - ミニブレッドボードは、背面の粘着テープを使って貼り付けてください
    - バッテリーボックスはsmaboの中に配置し、ジャンプワイヤーのみを外側に出して、ブレッドボードに挿す形で配線してください
      - 配線位置については、「配線」の章にて説明します
  
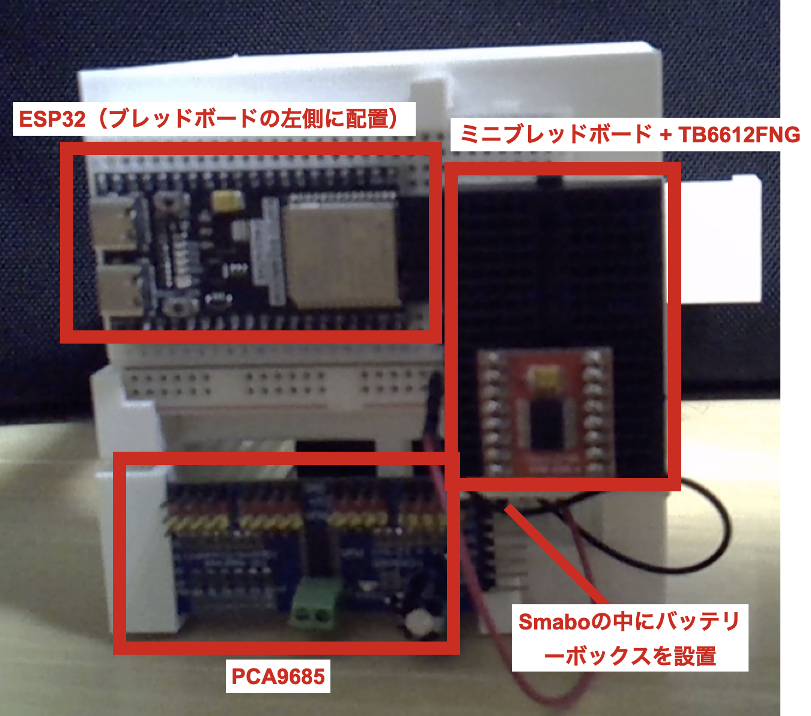
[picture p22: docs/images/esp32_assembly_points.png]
    

# 配線

!!! note ブレッドボードの+極について <!--重要なので、このNoteは特に目立つように-->
    SAD101購入時についていた、**+極のジャンプワイヤーは必ず外してください**。
    ついたままだと、**ESP32, アクチュエータが破損する**可能性があります。<!--太字を赤字にする-->
    

<br>

今回は、アクチュエータなどは動かさないため、以降の準備として「乾電池バッテリーの配線」のみを行います。

※ 下記表において、「接続先1」と「接続先2」は、両者が回路的に直接繋がっていることを指します。

| 接続先1 | 接続先2 | 補足 |
| --- | --- | --- |
| 乾電池バッテリーボックスの+極 |  ブレッドボードの+極の**右側**<!--太字はhtmlにする際は赤色に--> | 以降、右側を6V電圧として扱うため注意 | 
| 乾電池バッテリーボックスの-極 | ブレッドボードの-極  | - | 
| ESP32の5V電源 | ブレッドボードの+極の**左側**<!--太字はhtmlにする際は赤文字に--> | 以降、左側を5V電圧として扱うため注意 | 
| ESP32のGND | ブレッドボードの-極 | - | 

先述したように、+極は右側と左側で扱う電圧が異なるため
- 今後の配線で、**+極の片方に6V, 5V電源を混在させると、ESP32やアクチュエータが破損する原因になる**<!--htmlにする際は、ここの太字部分を赤字にしてください-->

ため、配線の際は十分に注意してください。

<br>

ESP32-DevKitCの場合の配線図は、以下になります。

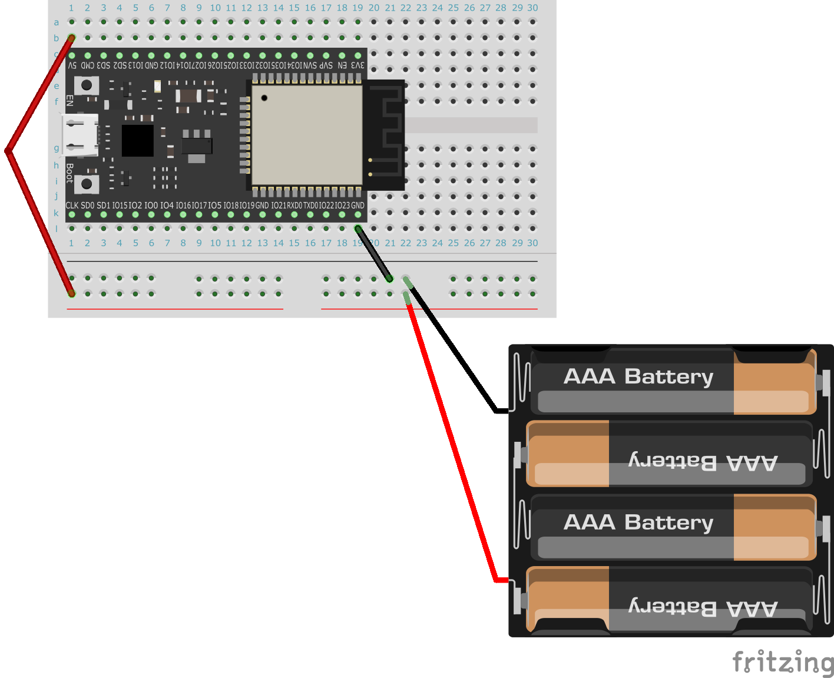
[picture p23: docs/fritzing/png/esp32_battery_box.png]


# 動作手順

## 起動手順

<!--htmlに変換する際は、startup.md の中で、「smabo-brainの起動」「smabo-webの起動」「smabo-brain <-> smabo-webの接続」「smabo-brain <-> esp32の接続」「smabo-web <-> esp32の接続」のみをフィルタしたものを表示すること-->

<!--
htmlに変換する際、「起動手順」へのリンク（startup.html）はクリックでポップアップ（モーダル）表示される。docs.js が a[href$="startup.html"] を捕捉して startup.html の .doc-content をモーダルに描画する。
ポップアップでは、リンクの data-steps 属性（startup.html の各 h2 の id をカンマ区切りで列挙）に挙げた手順だけを表示する。表示対象（data-steps）はこのページでは以下:
<a href="startup.html" data-steps="smabo-brainの起動,smabo-webの起動,smabo-brain---smabo-webの接続,smabo-brain---esp32の接続,smabo-web---esp32の接続">こちらの起動手順</a>
（JS 無効時は data-steps が無視され、通常のページ遷移になる）
-->

「[こちらの起動手順](./startup.md)」の内容を実行してください。

<br>

各種プログラムの起動、通信が確認できればOKです。

# 次回

次回は、以下ロードマップの

- [ハンド](./hand.md)
- [首振り](./neck.md)
- [移動ロボット](./mobile.md)
- [ロボットアーム](./arm.md)
- [smabo-brain-ros](./smabo-brain-ros.md)

について解説します。

<!--
htmlに変換する際は、以下のsvgファイルの代わりに、roadmap.htmlに記載してあるロードマップを添付すること。ただし、次回につながるノードをハイライトした状態にすること。また、roadmap.htmlに記載のロードマップの0.5倍のサイズとすること。
-->



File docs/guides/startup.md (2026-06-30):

<!--
以下は、md -> html 生成の際の指示（html生成時に直接出力する箇所ではない。以降、コメントアウトしてある箇所は、html生成時の注意事項が記載してあるものとする）

- markdownにて記載した文章は、誤字・脱字を除き、一切省略せずに、全く同じ文章でhtmlに反映すること（改行のタイミングなども含む）
    - 追記、修正した方がいい文章があった場合は、必ずユーザーに確認した上で、了承を得られた場合のみmarkdown, htmlともに修正すること
- 誤字、脱字があった場合は、markdown,html両方とも修正すること
- 表記揺れがあった場合は、どちらに統一するかユーザー側に確認したのちに、markdown, htmlともに、指定された表記に統一されるように修正すること
- 処理内容などに言及する部分に関しては、間違いがないか（コードが存在する場合は）コードの内容と照らし合わせて確認すること。その際、不整合があった場合は、ユーザー側に確認した上で了承が得られたら、markdown,htmlともに修正すること
- その他不正確な内容が含まれている場合は、ユーザー側に確認した上で了承が得られたら、markdown,htmlともに修正すること
-->

# 目次 <!-- omit in toc -->

- [smabo-brainの起動](#smabo-brainの起動)
- [smabo-webの起動](#smabo-webの起動)
- [smabo-brain \<-\> smabo-webの接続](#smabo-brain---smabo-webの接続)
- [smabo-appの接続](#smabo-appの接続)
- [smabo-brain \<-\> esp32の接続](#smabo-brain---esp32の接続)
- [smabo-web \<-\> esp32の接続](#smabo-web---esp32の接続)

<!--
本ページ（startup.html）は単独ページとしても開けるが、各ガイドの「起動手順」リンクからはポップアップ（モーダル）でも表示される。docs.js が本ページの .doc-content だけを取り出してモーダルに描画するため、ヘッダ/フッタ等のページ外枠に依存しない自己完結した内容にしておくこと。
-->

<!--強調する感じで-->
スマホ、PC、SBC、ESP32は全て「同一ネットワーク」に接続した状態で、以下手順を実行してください。

# smabo-brainの起動

最初に、PC/SBCからsmabo-brainを起動します。

```bash
cd ~/smabo-brain
```

```bash
python3 -m brain
```

# smabo-webの起動

次に、PCからsmabo-webを起動します。

```bash
cd ~/smabo-web
```
```bash
npm run dev
```

この状態で、ブラウザから`http://localhost:5173`にアクセスしてください。

# smabo-brain <-> smabo-webの接続

smabo-webアクセス時に、右下に「Brain connected」と表示されればOKです。

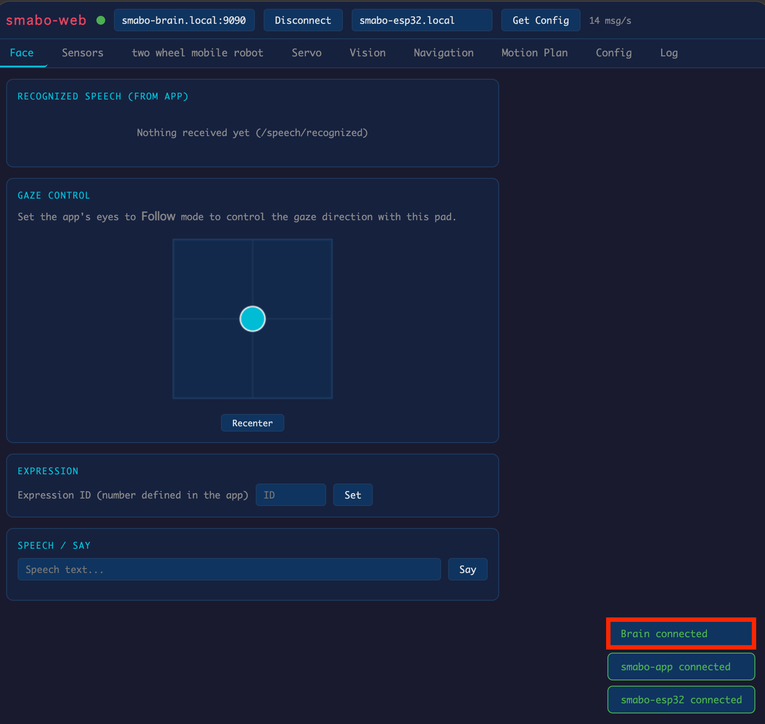
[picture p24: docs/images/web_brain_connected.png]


# smabo-appの接続

smabo-appを起動し、しばらくして「Brain connected」と表示されればOKです。

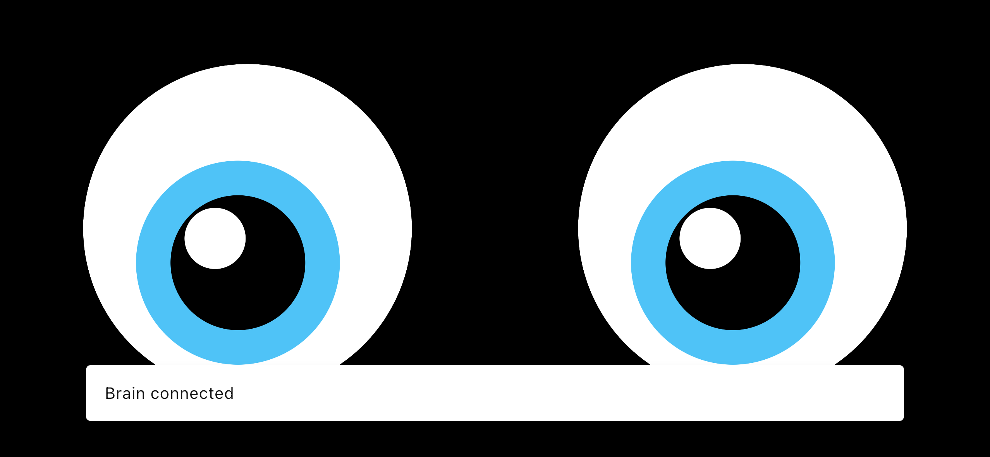
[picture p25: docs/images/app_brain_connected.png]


# smabo-brain <-> esp32の接続

「WS (brain <-> ESP32)」の右側にある「Ping」ボタンをクリックし、OKと表示されれば良いです。

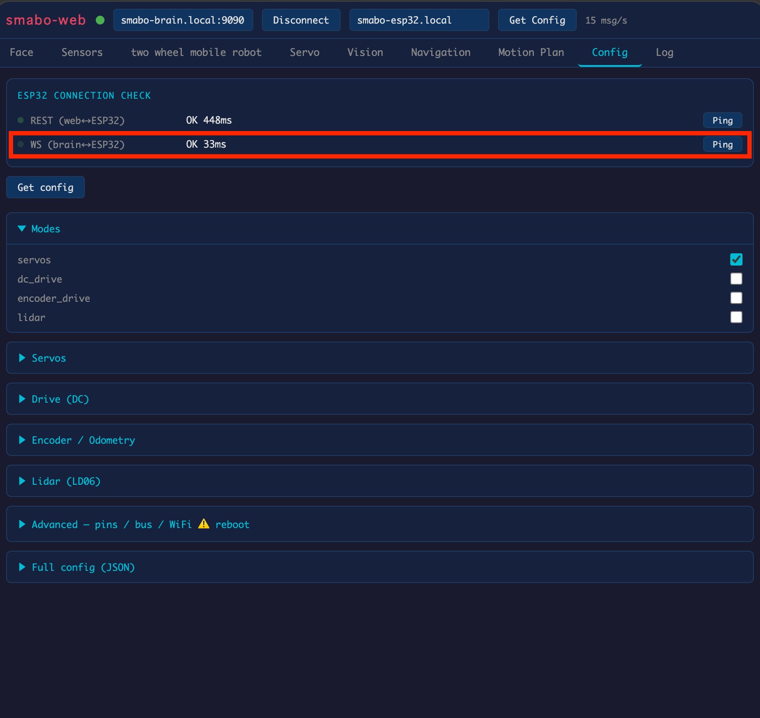
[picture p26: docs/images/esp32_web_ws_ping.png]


!!! note 接続できなかった場合
    上記手順で通信の疎通が失敗した場合は、`config.json`のWiFiの設定を確認してください。もし、間違っている箇所があった場合、修正した後esp32に再書き込みしてください。

# smabo-web <-> esp32の接続

「Config」タブの「REST(web <-> ESP32)」の右の「Ping」ボタンをクリックし、OKと表示されれば良いです。

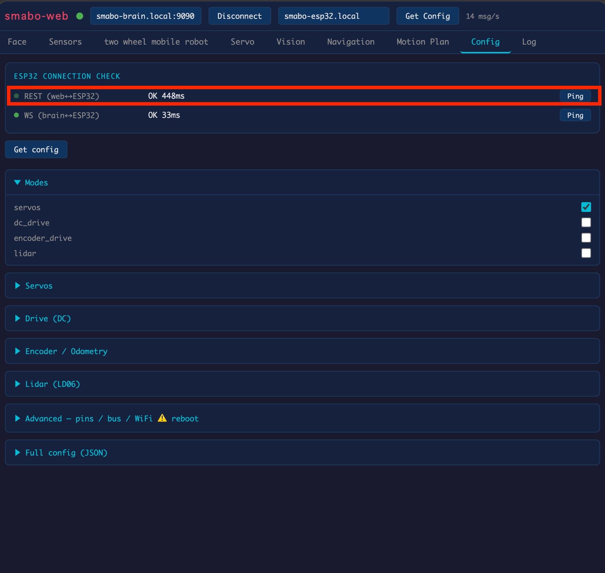
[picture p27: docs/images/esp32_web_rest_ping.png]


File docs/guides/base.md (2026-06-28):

<!--
以下は、md -> html 生成の際の指示（html生成時に直接出力する箇所ではない。以降、コメントアウトしてある箇所は、html生成時の注意事項が記載してあるものとする）

- markdownにて記載した文章は、誤字・脱字を除き、一切省略せずに、全く同じ文章でhtmlに反映すること（改行のタイミングなども含む）
    - 追記、修正した方がいい文章があった場合は、必ずユーザーに確認した上で、了承を得られた場合のみmarkdown, htmlともに修正すること
- 誤字、脱字があった場合は、markdown,html両方とも修正すること
- 表記揺れがあった場合は、どちらに統一するかユーザー側に確認したのちに、markdown, htmlともに、指定された表記に統一されるように修正すること
- 処理内容などに言及する部分に関しては、間違いがないか（コードが存在する場合は）コードの内容と照らし合わせて確認すること。その際、不整合があった場合は、ユーザー側に確認した上で了承が得られたら、markdown,htmlともに修正すること
- その他不正確な内容が含まれている場合は、ユーザー側に確認した上で了承が得られたら、markdown,htmlともに修正すること
-->

# 目次 <!-- omit in toc -->

- [ロードマップ](#ロードマップ)
- [概要](#概要)
- [必要パーツ](#必要パーツ)
- [smabo-hardwareリポジトリのダウンロード](#smabo-hardwareリポジトリのダウンロード)
- [スマホ固定用パーツの修正](#スマホ固定用パーツの修正)
  - [スマホのサイズ計測](#スマホのサイズ計測)
  - [パーツの寸法修正](#パーツの寸法修正)
    - [左右固定用パーツ](#左右固定用パーツ)
    - [上下固定用パーツ](#上下固定用パーツ)
  - [パーツのエクスポート](#パーツのエクスポート)
- [パーツの印刷](#パーツの印刷)
- [組み立て手順](#組み立て手順)
  - [各種パーツの取り付け](#各種パーツの取り付け)
  - [スマホの取り付け](#スマホの取り付け)
- [完成系](#完成系)
- [次回](#次回)

# ロードマップ

本ページは、以下ロードマップ「ベースパーツの作成」のガイドページです。

また、本ページは「[smabo-app](./smabo-app.md)」のガイドを実施している前提で話を進めます。

<!--
htmlに変換する際は、以下のsvgファイルの代わりに、roadmap.htmlに記載してあるロードマップを添付すること。ただし、本ページのノードをハイライトした状態にすること。また、roadmap.htmlに記載のロードマップの0.5倍のサイズとすること。
-->



# 概要

本ページでは「ベースパーツの作成」手順について解説します。

<br>

具体的には、以下の内容を実施します。

- 自分のスマホのサイズに合わせた3Dモデルの修正
- ベースパーツの3Dプリンタによる印刷

# 必要パーツ

本機能の実装に必要なパーツを以下に記載します。

| 部品名 | 商品URL | 備考 |
| --- | --- | --- |
| スマートフォン | - | お手持ちのスマートフォン |

# smabo-hardwareリポジトリのダウンロード

最初に、
- smaboで使用する「3Dパーツのstl, stepファイル」

が管理された、以下のsmabo-hardwareリポジトリをPCにダウンロードします。

https://github.com/smabo-smartphone-robot/smabo-hardware

!!! note
    smabo-hardwareリポジトリは、全てのパーツが格納されており、今後も使用するので、管理しやすい場所にDLしてください。

# スマホ固定用パーツの修正

smaboでは、スマートフォンを固定することができますが、スマホのサイズは人それぞれ異なるため、ここでは

- スマホ固定用パーツのサイズの修正手順

について解説します。

## スマホのサイズ計測

最初に、お手持ちのスマホの
- 長手方向
- 短手方向
- 厚み（カメラが出っ張っている場合は、一番分厚い箇所）」

を「mm単位」で計測してください（カバーをつけている場合は、カバー込みのサイズ）。

!!! note ノギス
    計測の際は、「公式サイトのカタログスペックを確認する」「定規で測る」などの方法がありますが、
    - ノギスを使用する

    という方法もおすすめです。
    <br>
    ノギスは、定規よりも高精度にサイズを計測できる道具です。
    ロボットの作成ではよく使用するので、興味がある方は購入を検討ください。

## パーツの寸法修正

次に、各パーツをお手持ちのスマホに合わせて寸法を修正する手順を説明します。

!!! note CADソフト
    使用するCADソフトはなんでも良いですが、ここではfusion360を使用する場合の手順を補足欄に記載します。

### 左右固定用パーツ

「smabo-hardware/step/smart_phone/smartphone_long_width_75_height_11.step」をインポートし、「パーツの先端〜内側面」までの長さが
- 「スマホの長手方向/2」+ 1mm

になるように調整します。

!!! note fusion360の場合の具体的な手順
    左側タブの「Upload」をクリックします。
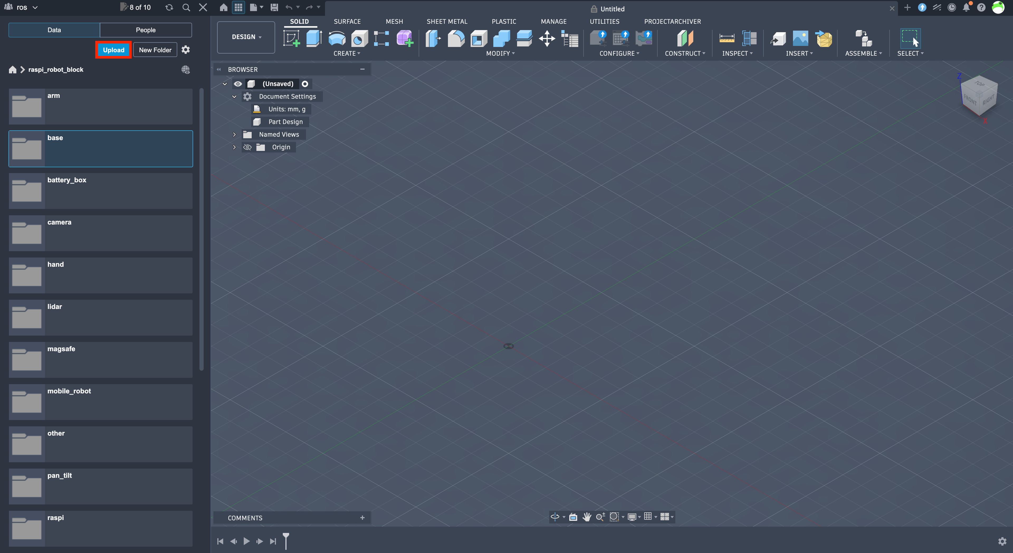
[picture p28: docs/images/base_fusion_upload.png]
    

    <br>

    「Select Files」をクリックします。
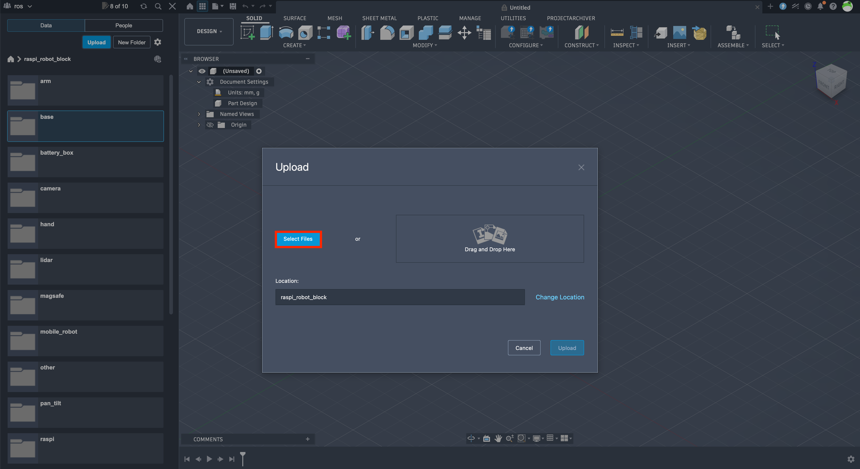
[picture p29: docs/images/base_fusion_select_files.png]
    

    <br>

    「smartphone_long_width_75_height_11.step」を選択します。
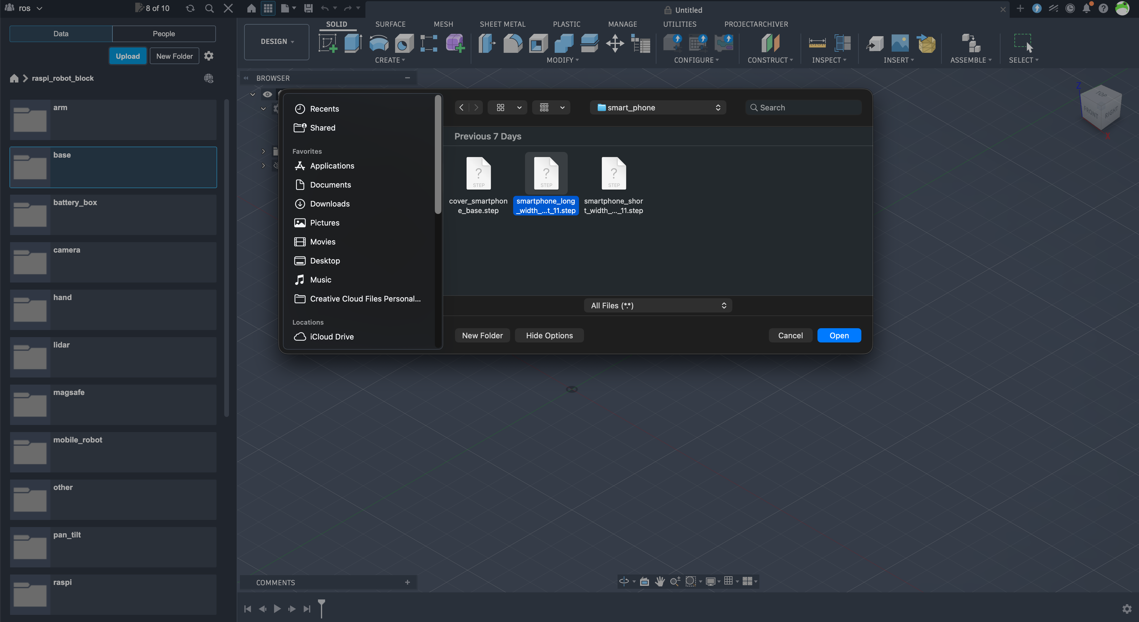
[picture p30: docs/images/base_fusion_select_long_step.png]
    

    <br>

    インポートが完了したら、smartphone_long_width_75_height_11を開きます。

    <br>

    外側面を選択した状態で「Extrude」をクリックします。
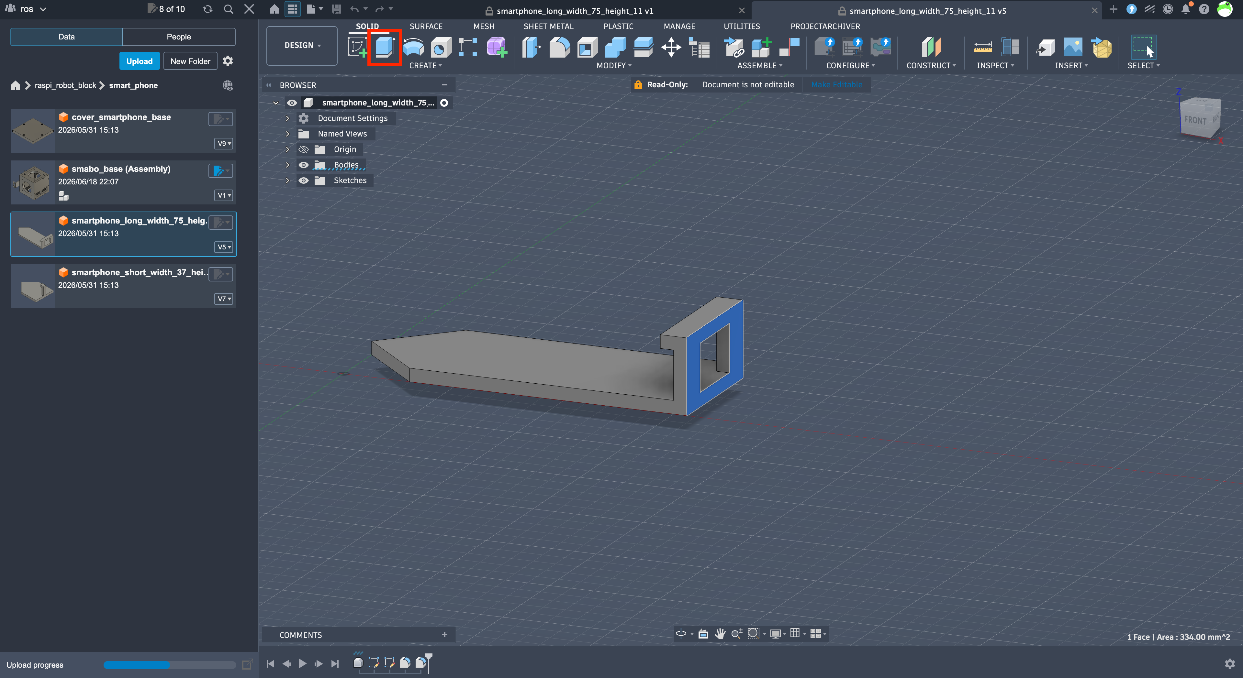
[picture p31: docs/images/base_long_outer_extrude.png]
    

    <br>

    長さを「スマホの長手方向/2」 + 3 + 1 に設定します。
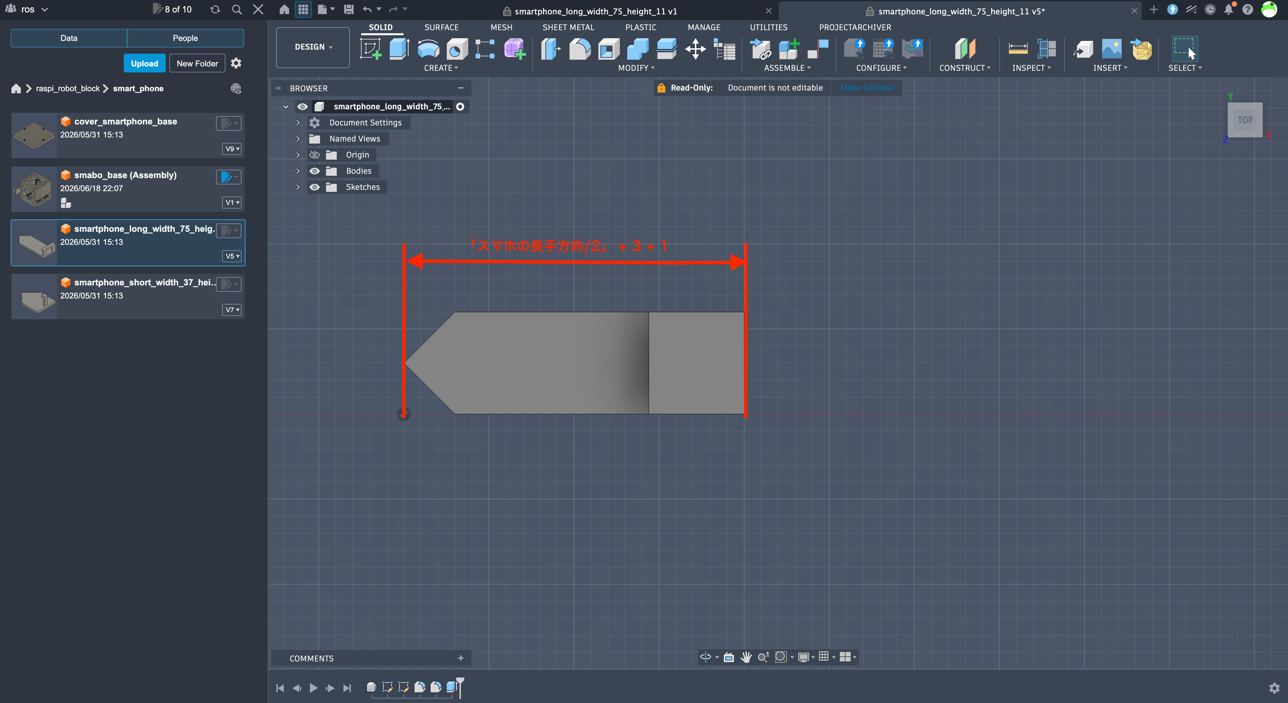
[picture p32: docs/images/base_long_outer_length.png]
    

    <br>

    同様に内側面を選択した状態で「Extrude」をクリックします。
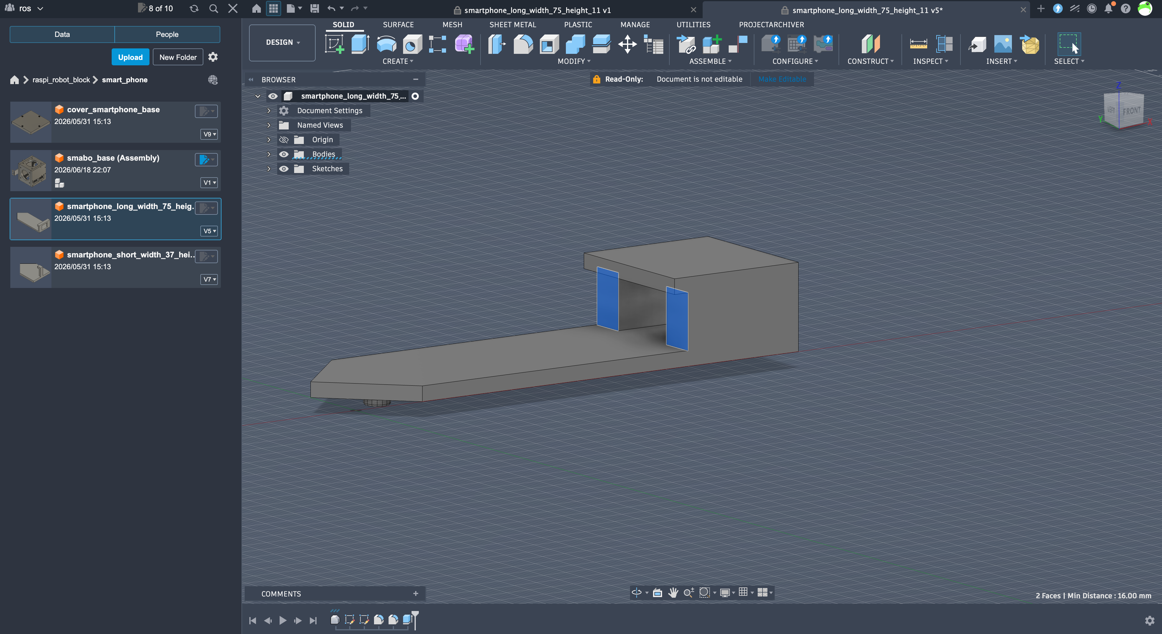
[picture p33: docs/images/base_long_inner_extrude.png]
    

    <br>

    長さを「スマホの長手方向/2」 +  1 に設定します。
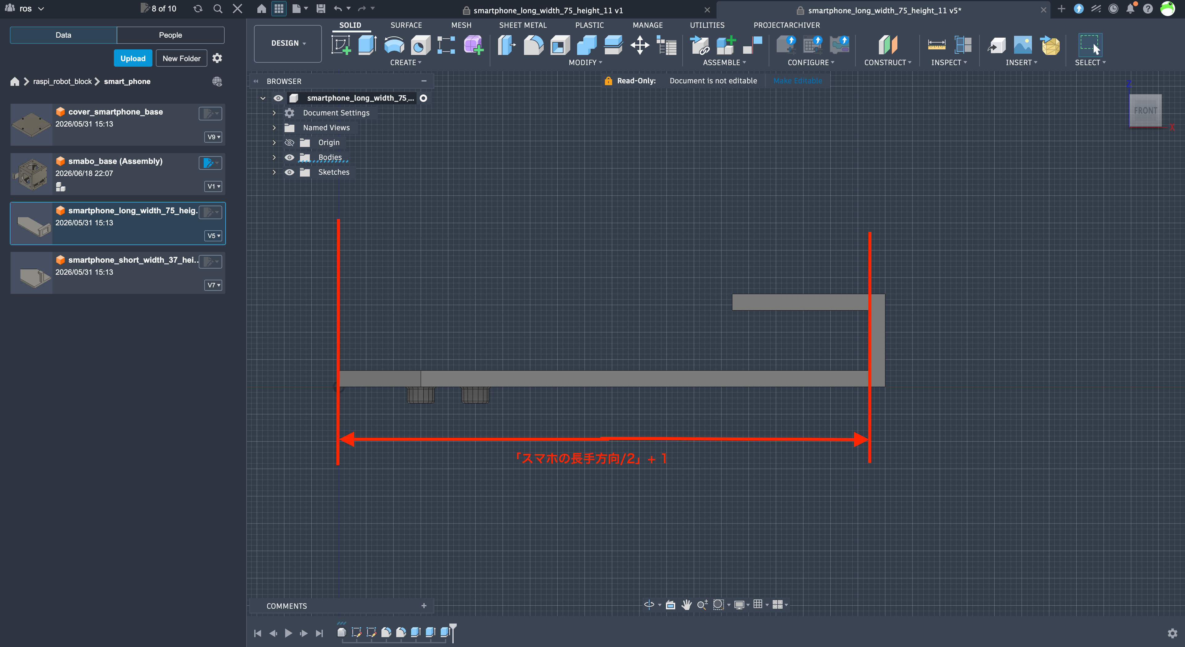
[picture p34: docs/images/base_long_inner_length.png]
    

<br>

<br>

また、「固定部の上側面〜下側面」までの長さは
- 「スマホの厚み」+ 1mm

になるように調整します。

!!! note fusion360の場合の具体的な手順
    上面を選択し、「Extrude」をクリックします。
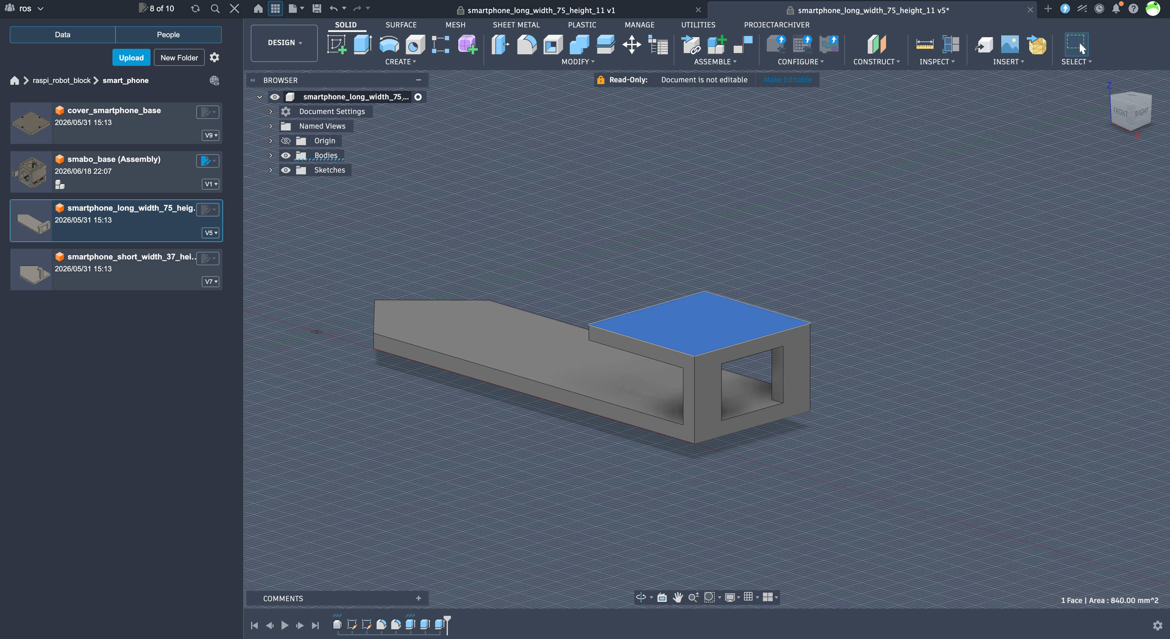
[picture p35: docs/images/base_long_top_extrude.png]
    

    <br>

    長さを「スマホの厚さ」+ 1 + 3 に設定します。
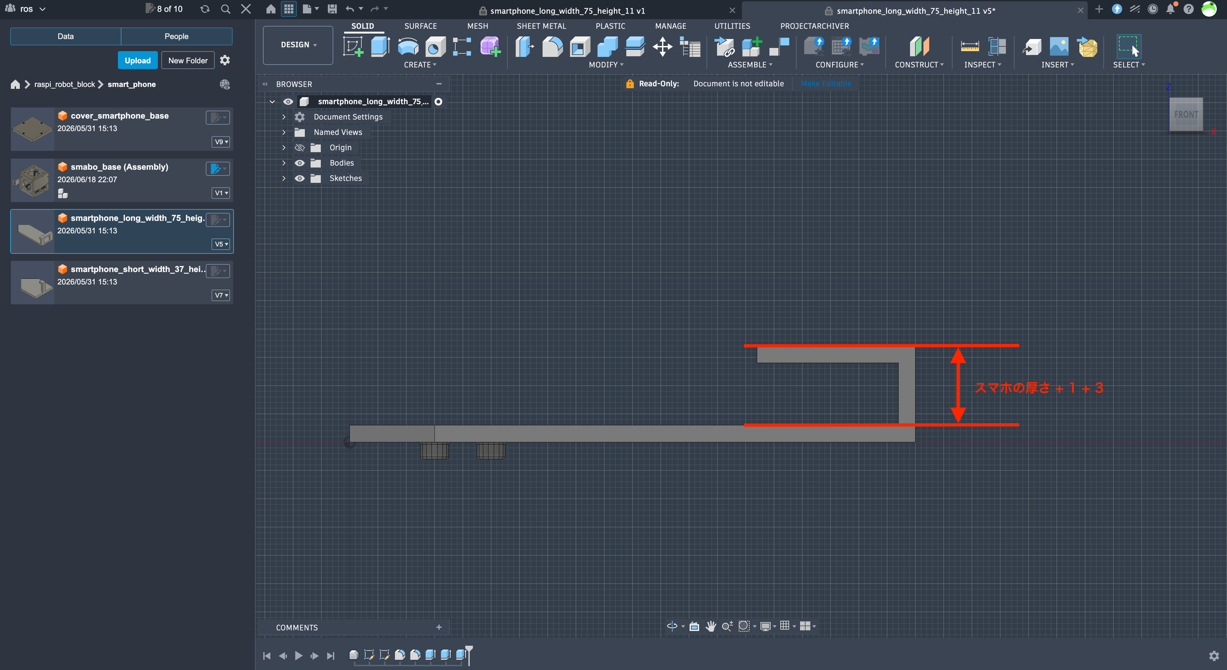
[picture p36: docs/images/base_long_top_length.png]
    

    <br>

    下面を選択し、「Extrude」をクリックします。
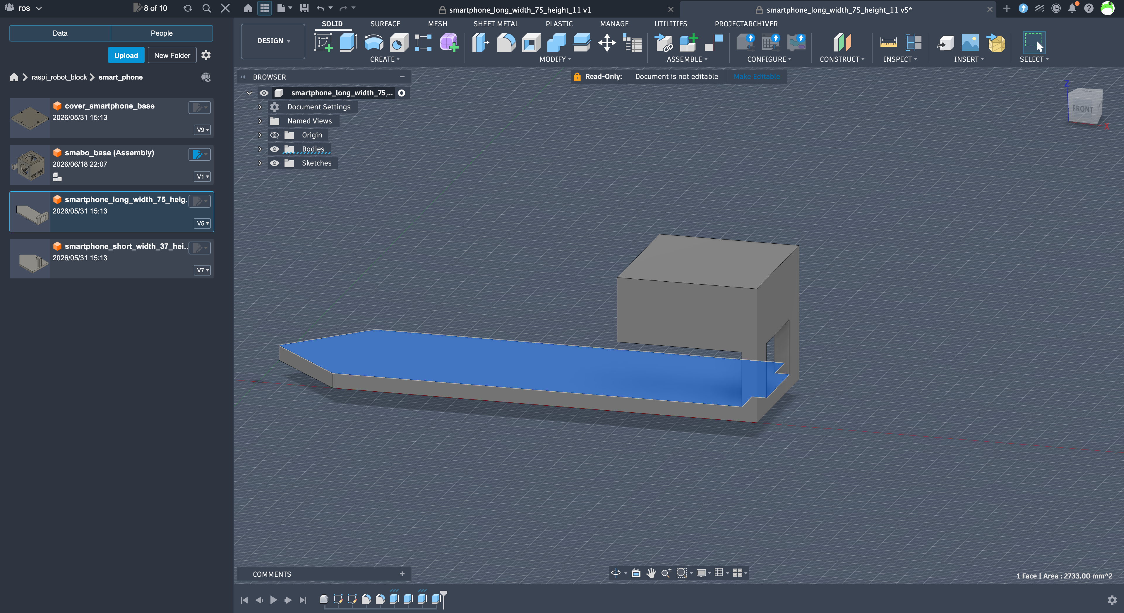
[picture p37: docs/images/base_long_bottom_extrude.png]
    

    <br>

    長さを「スマホの厚さ」+ 1 に設定します。
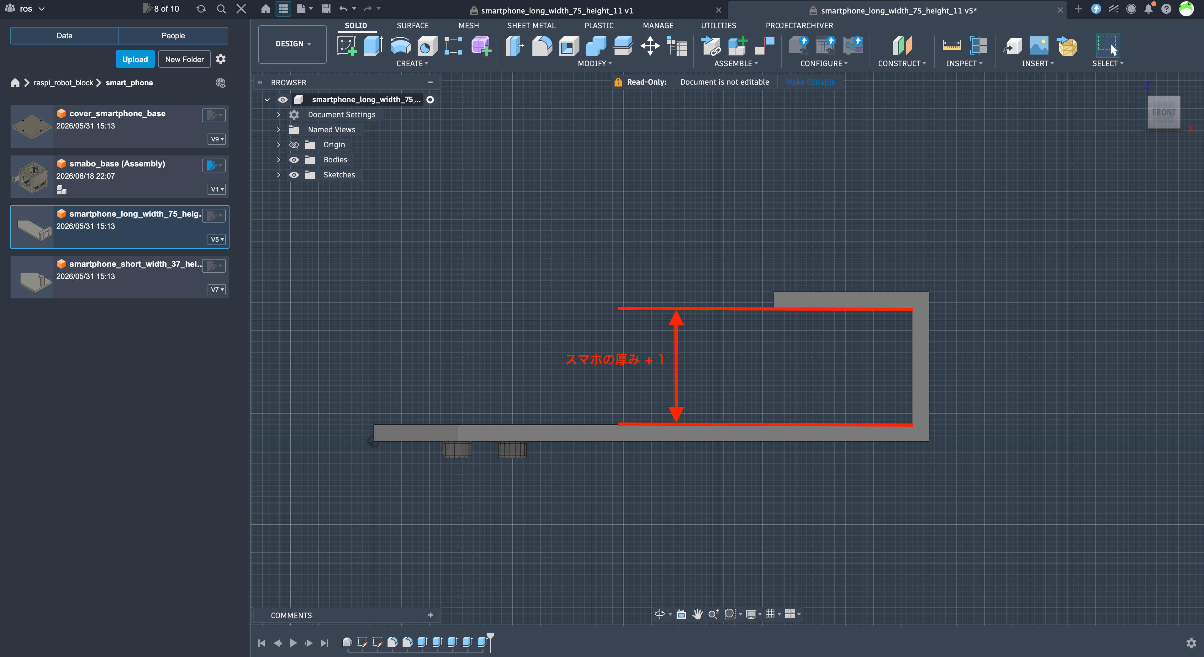
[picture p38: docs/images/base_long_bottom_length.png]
    

### 上下固定用パーツ

「smabo-hardware/step/smart_phone/smartphone_short_width_37_height_11.step」をインポートし、「パーツの先端〜内側面」までの長さが
- 「スマホの短手方向/2」+ 1mm

になるように調整します。

!!! note fusion360の場合の具体的な手順
    「左右固定パーツ」の時と同様の手順で、「スマホの短手方向」を基準にサイズを調整します。

<br>

<br>

また、「固定部の上側面〜下側面」までの長さは
- 「スマホの厚み」+ 1mm

になるように調整します。

!!! note fusion360の場合の具体的な手順
    「左右固定パーツ」の時と同様の手順でサイズを調整します。

## パーツのエクスポート

パーツのサイズ調整が完了したら、stlファイルとしてエクスポートします。

!!! note fusion360の場合の具体的な手順
    左上から「File」->「Export」を選択します。
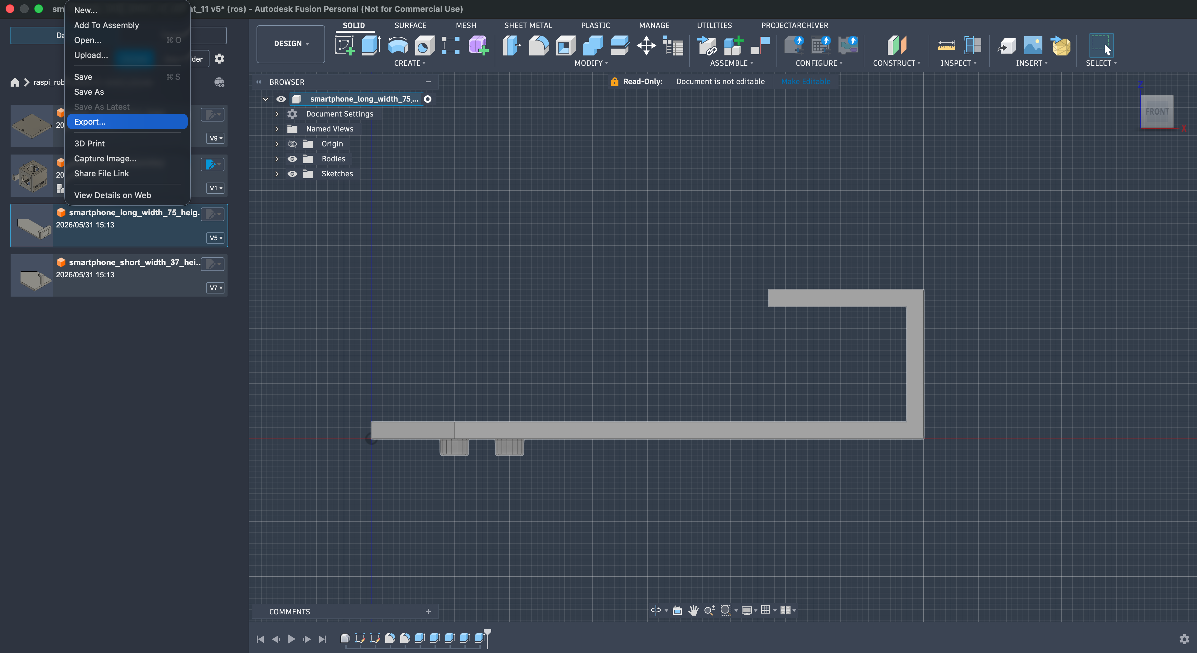
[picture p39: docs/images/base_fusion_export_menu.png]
    

    <br>

    それぞれ、以下のように設定し「Export」を選択し、ファイルをエクスポートします。
    - Name：任意の名称
    - Type：stl
    - Location：任意の場所

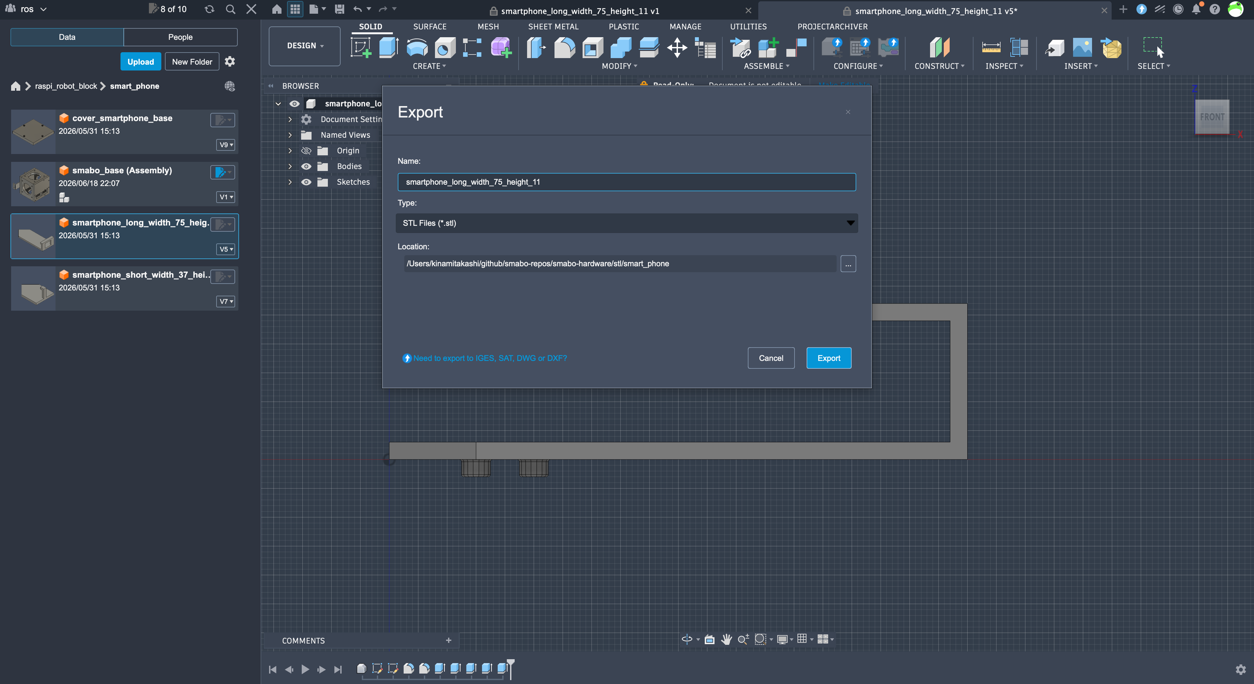
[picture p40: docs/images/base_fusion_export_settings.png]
    

# パーツの印刷

今回、新たに追加されるパーツを3Dプリンタで印刷します。

!!! note
    3Dプリンタは機種によって「印刷する際に使用するソフト」が異なるため、ここでは具体的な設定手順ではなく、ポイントのみを記載します。

<br>

<br>

以下のパーツを図の向きに設定して、印刷してください。

!!! note  印刷の際の注意点
    - パーツのつけ外しの際に、根本から折れにくくするため、凸部は横向きにして印刷
    - サポート材は必ずONにした状態で印刷

- smabo-hardware/stl/base/base.stl
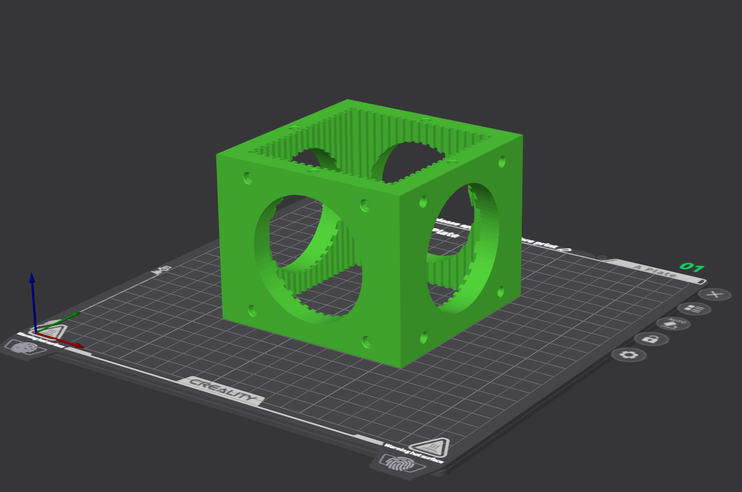
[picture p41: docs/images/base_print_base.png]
    

<br>

- smabo-hardware/stl/base/cover_back_bread_board.stl
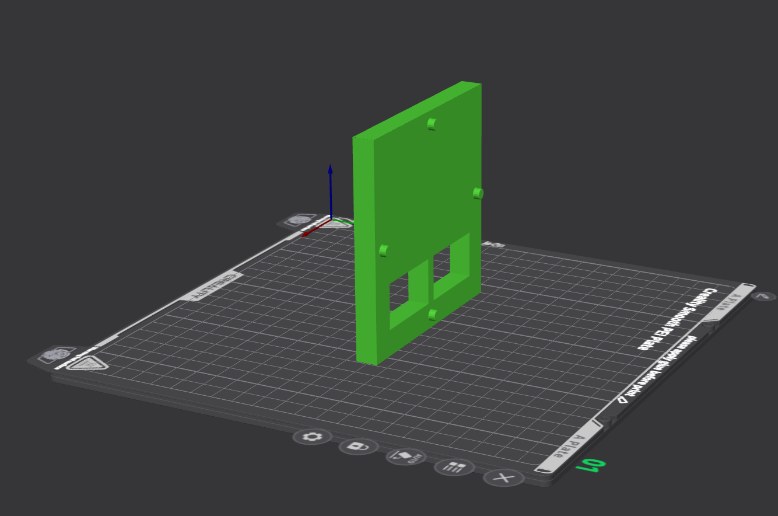
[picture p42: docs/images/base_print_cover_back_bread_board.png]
    

<br>

- smabo-hardware/stl/smart_phone/cover_smartphone_base.stl
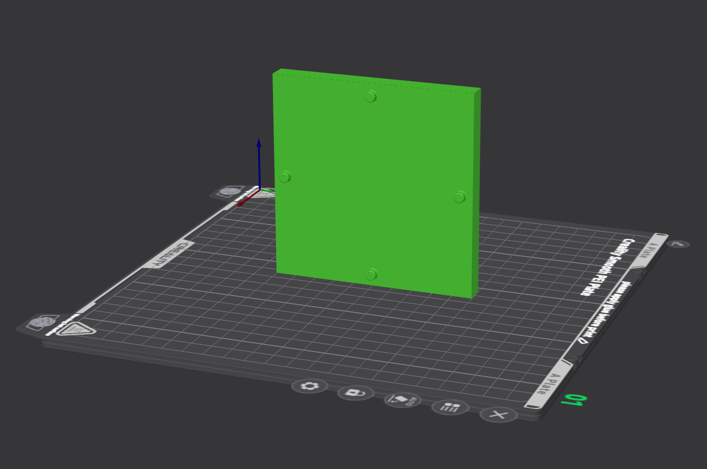
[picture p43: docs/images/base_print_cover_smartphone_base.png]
    

<br>

- smabo-hardware/stl/smart_phone/smartphone_long_width_75_height_11.stl（元サイズからお持ちのスマホ用に調整したもの） × 2
  - 左右で同じパーツを使用するため2つ印刷します
    

<br>

- smabo-hardware/stl/smart_phone/smartphone_short_width_37_height_11.stl（元サイズからお持ちのスマホ用に調整したもの）× 2
  - 上下で同じパーツを使用するため2つ印刷します
    

# 組み立て手順

## 各種パーツの取り付け

以下動画のように、必要パーツを組み立てます。

※ 動画には、前回までに印刷したパーツも含まれます

<!--ここに「docs/assembly_movie/base.html」の組み立て動画を埋め込む
-->

!!! note 組み立ての際のポイント
    上下のパーツに関しては、頻繁に取り外しをする想定ならば
    - 下のパーツだけ取り付けて、スマホはスライドしてつけ外しする
    
    ような形にしてもOKです。
    （この場合、もちろん上下逆さまにひっくり返すとスマホが落ちるので注意してください）。

## スマホの取り付け

スマホがちゃんと取り付けられるか確認しましょう。

# 完成系

今回作成したロボットの完成系は下図のようになります。


# 次回

次回は、以下ロードマップの

- [smabo-esp32](./smabo-esp32.md)

について解説します。

<!--
htmlに変換する際は、以下のsvgファイルの代わりに、roadmap.htmlに記載してあるロードマップを添付すること。ただし、次回につながるノードをハイライトした状態にすること。また、roadmap.htmlに記載のロードマップの0.5倍のサイズとすること。
-->



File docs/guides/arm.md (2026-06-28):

<!--
以下は、md -> html 生成の際の指示（html生成時に直接出力する箇所ではない。以降、コメントアウトしてある箇所は、html生成時の注意事項が記載してあるものとする）

- markdownにて記載した文章は、誤字・脱字を除き、一切省略せずに、全く同じ文章でhtmlに反映すること（改行のタイミングなども含む）
    - 追記、修正した方がいい文章があった場合は、必ずユーザーに確認した上で、了承を得られた場合のみmarkdown, htmlともに修正すること
- 誤字、脱字があった場合は、markdown,html両方とも修正すること
- 表記揺れがあった場合は、どちらに統一するかユーザー側に確認したのちに、markdown, htmlともに、指定された表記に統一されるように修正すること
- 処理内容などに言及する部分に関しては、間違いがないか（コードが存在する場合は）コードの内容と照らし合わせて確認すること。その際、不整合があった場合は、ユーザー側に確認した上で了承が得られたら、markdown,htmlともに修正すること
- その他不正確な内容が含まれている場合は、ユーザー側に確認した上で了承が得られたら、markdown,htmlともに修正すること
-->

# 目次 <!-- omit in toc -->

- [ロードマップ](#ロードマップ)
- [できること](#できること)
- [構成](#構成)
- [必要パーツ](#必要パーツ)
- [パーツの印刷](#パーツの印刷)
- [組み立て手順](#組み立て手順)
- [配線](#配線)
- [完成系](#完成系)
- [動作手順](#動作手順)
- [次回](#次回)

# ロードマップ

本ページは、以下ロードマップ「ロボットアーム」のガイドページです。

また、本ページは「[smabo-esp32](./smabo-esp32.md)」のガイドを実施している前提で話を進めます。

<!--
htmlに変換する際は、以下のsvgファイルの代わりに、roadmap.htmlに記載してあるロードマップを添付すること。ただし、本ページのノードをハイライトした状態にすること。また、roadmap.htmlに記載のロードマップの0.5倍のサイズとすること。
-->



# できること

本ページでは「ロボットアーム」機能の実装について解説します。

<br>

具体的には、以下の内容を実施します。

- ロボットアームパーツの印刷・組み立て
- サーボモータ4つによる、4軸アームの制御

!!! note サーボの割り当て
    ロボットアームはサーボモータ4つで構成され、smabo-esp32のデフォルト設定では
    - `arm_joint_1`：PCA9685 チャンネル3
    - `arm_joint_2`：PCA9685 チャンネル4
    - `arm_joint_3`：PCA9685 チャンネル5
    - `arm_joint_4`：PCA9685 チャンネル6

    が割り当てられています。軸数は、お手持ちのアームに合わせて増減できます。

# 構成

今回は、下図のようになります。

<!-- 以下の、smabo_sysytem_architecture.drawio.svgの代わりに、sysmap.jsをもとに作成したアーキテクチャ図を配置する。-->
<!-- 以下例のように記述するので、ハイライトするノードと矢印、およびラベルに記述する内容を確認し、アーキテクチャ図を作成してください -->
<!-- 例）コンポーネント1 -[websocket]-> コンポーネント2：データ種類1, データ種類2 -->
<!-- 今回の、具体的な構成は以下になります。 -->
<!-- smabo-brain -[websocket]-> smabo-esp32 : サーボ制御 -->



# 必要パーツ

本機能の実装に必要なパーツを以下に記載します。

| 部品名 | 商品URL | 備考 |
| --- | --- | --- |
| サーボモータ（SG90等） × 4 | link | アームの各関節で1つずつ使用します |

# パーツの印刷

今回、新たに追加されるパーツを3Dプリンタで印刷します。

!!! note
    3Dプリンタは機種によって「印刷する際に使用するソフト」が異なるため、ここでは具体的な設定手順ではなく、ポイントのみを記載します。
<br>

以下のパーツを図の向きに設定して、印刷してください。

!!! note  印刷の際の注意点
    - パーツのつけ外しの際に、根本から折れにくくするため、凸部は横向きにして印刷
    - サポート材は必ずONにした状態で印刷

- ***.stl
    ここに画像

<br>

- ***.stl
    ここに画像

# 組み立て手順

以下動画のように、必要パーツを組み立てます。

※ 動画には、前回までに印刷したパーツも含まれます

<!--ここに、ロボットアームの組み立て動画を置いてください-->

!!! note 組み立ての際のポイント
    oooo

# 配線

!!! note ブレッドボードの+極について <!--重要なので、このNoteは特に目立つように-->
    SAD101購入時についていた、**+極のジャンプワイヤーは必ず外してください**。
    ついたままだと、**ESP32, アクチュエータが破損する**可能性があります。<!--太字を赤字にする-->
    

<br>

サーボモータは、PCA9685の各チャンネルに接続します。

※ 下記表において、「接続先1」と「接続先2」は、両者が回路的に直接繋がっていることを指します。

| 接続先1 | 接続先2 | 補足 |
| --- | --- | --- |
| `arm_joint_1`のサーボ | PCA9685のチャンネル3 | - |
| `arm_joint_2`のサーボ | PCA9685のチャンネル4 | - |
| `arm_joint_3`のサーボ | PCA9685のチャンネル5 | - |
| `arm_joint_4`のサーボ | PCA9685のチャンネル6 | - |

<br>

ESP32-DevKitCの場合の、具体的な配線図は、以下になります。

!!! note 配線の際のポイント
    oooo

# 完成系

今回作成したロボットの完成系は下図のようになります。

# 動作手順

以下手順で、動作の確認を行います。

smabo-webの「Servo」タブから、`arm_joint_1`〜`arm_joint_4`のスライダーを動かし、各関節が動けばOKです。

# 次回

次回は、以下ロードマップの

- [動作計画](./plan.md)

について解説します。

<!--
htmlに変換する際は、以下のsvgファイルの代わりに、roadmap.htmlに記載してあるロードマップを添付すること。ただし、次回につながるノードをハイライトした状態にすること。また、roadmap.htmlに記載のロードマップの0.5倍のサイズとすること。
-->



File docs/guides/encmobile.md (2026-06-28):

<!--
以下は、md -> html 生成の際の指示（html生成時に直接出力する箇所ではない。以降、コメントアウトしてある箇所は、html生成時の注意事項が記載してあるものとする）

- markdownにて記載した文章は、誤字・脱字を除き、一切省略せずに、全く同じ文章でhtmlに反映すること（改行のタイミングなども含む）
    - 追記、修正した方がいい文章があった場合は、必ずユーザーに確認した上で、了承を得られた場合のみmarkdown, htmlともに修正すること
- 誤字、脱字があった場合は、markdown,html両方とも修正すること
- 表記揺れがあった場合は、どちらに統一するかユーザー側に確認したのちに、markdown, htmlともに、指定された表記に統一されるように修正すること
- 処理内容などに言及する部分に関しては、間違いがないか（コードが存在する場合は）コードの内容と照らし合わせて確認すること。その際、不整合があった場合は、ユーザー側に確認した上で了承が得られたら、markdown,htmlともに修正すること
- その他不正確な内容が含まれている場合は、ユーザー側に確認した上で了承が得られたら、markdown,htmlともに修正すること
-->

# 目次 <!-- omit in toc -->

- [ロードマップ](#ロードマップ)
- [できること](#できること)
- [構成](#構成)
- [必要パーツ](#必要パーツ)
- [パーツの印刷](#パーツの印刷)
- [組み立て手順](#組み立て手順)
- [配線](#配線)
- [完成系](#完成系)
- [動作手順](#動作手順)
- [次回](#次回)

# ロードマップ

本ページは、以下ロードマップ「エンコーダ付移動ロボット」のガイドページです。

また、本ページは「[移動ロボット](./mobile.md)」のガイドを実施している前提で話を進めます。

<!--
htmlに変換する際は、以下のsvgファイルの代わりに、roadmap.htmlに記載してあるロードマップを添付すること。ただし、本ページのノードをハイライトした状態にすること。また、roadmap.htmlに記載のロードマップの0.5倍のサイズとすること。
-->



# できること

本ページでは「エンコーダ付移動ロボット」機能の実装について解説します。

<br>

具体的には、以下の内容を実施します。

- 車輪へのエンコーダの取り付け
- エンコーダによる走行距離の計測（オドメトリ）

!!! note オドメトリの仕組み
    smabo-esp32はエンコーダから左右の車輪速度を計算し、`/wheel_vel`（left/right/dt）としてsmabo-brainへ送信します。
    smabo-brainはこれを積分して自己位置（x/y/θ）を求め、`/odom`として配信します。
    エンコーダ走行を使う場合は、smabo-esp32の`modes.encoder_drive`を有効にします。

# 構成

今回は、下図のようになります。

<!-- 以下の、smabo_sysytem_architecture.drawio.svgの代わりに、sysmap.jsをもとに作成したアーキテクチャ図を配置する。-->
<!-- 以下例のように記述するので、ハイライトするノードと矢印、およびラベルに記述する内容を確認し、アーキテクチャ図を作成してください -->
<!-- 例）コンポーネント1 -[websocket]-> コンポーネント2：データ種類1, データ種類2 -->
<!-- 今回の、具体的な構成は以下になります。 -->
<!-- smabo-brain -[websocket]-> smabo-esp32 : 速度指令 -->
<!-- smabo-esp32 -[websocket]-> smabo-brain : ホイール速度 -->



# 必要パーツ

本機能の実装に必要なパーツを以下に記載します。

| 部品名 | 商品URL | 備考 |
| --- | --- | --- |
| ロータリーエンコーダ付きモータ または エンコーダ × 2 | link | 左右の車輪用 |

# パーツの印刷

今回、新たに追加されるパーツを3Dプリンタで印刷します。

!!! note
    3Dプリンタは機種によって「印刷する際に使用するソフト」が異なるため、ここでは具体的な設定手順ではなく、ポイントのみを記載します。
<br>

以下のパーツを図の向きに設定して、印刷してください。

!!! note  印刷の際の注意点
    - パーツのつけ外しの際に、根本から折れにくくするため、凸部は横向きにして印刷
    - サポート材は必ずONにした状態で印刷

- ***.stl
    ここに画像

<br>

- ***.stl
    ここに画像

# 組み立て手順

以下動画のように、必要パーツを組み立てます。

※ 動画には、前回までに印刷したパーツも含まれます

<!--ここに、エンコーダ付移動ロボットの組み立て動画を置いてください-->

!!! note 組み立ての際のポイント
    oooo

# 配線

!!! note ブレッドボードの+極について <!--重要なので、このNoteは特に目立つように-->
    SAD101購入時についていた、**+極のジャンプワイヤーは必ず外してください**。
    ついたままだと、**ESP32, アクチュエータが破損する**可能性があります。<!--太字を赤字にする-->
    

<br>

エンコーダは、smabo-esp32のデフォルト設定では、以下のピンが割り当てられています。

※ 下記表において、「接続先1」と「接続先2」は、両者が回路的に直接繋がっていることを指します。

| 接続先1 | 接続先2 | 補足 |
| --- | --- | --- |
| 左車輪エンコーダの`a` | ESP32のGPIO 34 | - |
| 左車輪エンコーダの`b` | ESP32のGPIO 35 | - |
| 右車輪エンコーダの`a` | ESP32のGPIO 36 | - |
| 右車輪エンコーダの`b` | ESP32のGPIO 39 | - |

<br>

ESP32-DevKitCの場合の、具体的な配線図は、以下になります。

!!! note 配線の際のポイント
    oooo

# 完成系

今回作成したロボットの完成系は下図のようになります。

# 動作手順

以下手順で、動作の確認を行います。

smabo-webの「Config」タブで`encoder_drive`を有効にし、台車を手で動かしたときに「two wheel mobile robot」タブのオドメトリ（位置・速度）やTrail Mapが更新されればOKです。

# 次回

次回は、以下ロードマップの

- [ナビゲーション](./nav.md)

について解説します。

<!--
htmlに変換する際は、以下のsvgファイルの代わりに、roadmap.htmlに記載してあるロードマップを添付すること。ただし、次回につながるノードをハイライトした状態にすること。また、roadmap.htmlに記載のロードマップの0.5倍のサイズとすること。
-->



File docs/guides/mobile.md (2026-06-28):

<!--
以下は、md -> html 生成の際の指示（html生成時に直接出力する箇所ではない。以降、コメントアウトしてある箇所は、html生成時の注意事項が記載してあるものとする）

- markdownにて記載した文章は、誤字・脱字を除き、一切省略せずに、全く同じ文章でhtmlに反映すること（改行のタイミングなども含む）
    - 追記、修正した方がいい文章があった場合は、必ずユーザーに確認した上で、了承を得られた場合のみmarkdown, htmlともに修正すること
- 誤字、脱字があった場合は、markdown,html両方とも修正すること
- 表記揺れがあった場合は、どちらに統一するかユーザー側に確認したのちに、markdown, htmlともに、指定された表記に統一されるように修正すること
- 処理内容などに言及する部分に関しては、間違いがないか（コードが存在する場合は）コードの内容と照らし合わせて確認すること。その際、不整合があった場合は、ユーザー側に確認した上で了承が得られたら、markdown,htmlともに修正すること
- その他不正確な内容が含まれている場合は、ユーザー側に確認した上で了承が得られたら、markdown,htmlともに修正すること
-->

# 目次 <!-- omit in toc -->

- [ロードマップ](#ロードマップ)
- [できること](#できること)
- [構成](#構成)
- [必要パーツ](#必要パーツ)
- [パーツの印刷](#パーツの印刷)
- [組み立て手順](#組み立て手順)
- [配線](#配線)
- [完成系](#完成系)
- [動作手順](#動作手順)
- [次回](#次回)

# ロードマップ

本ページは、以下ロードマップ「移動ロボット」のガイドページです。

また、本ページは「[smabo-esp32](./smabo-esp32.md)」のガイドを実施している前提で話を進めます。

<!--
htmlに変換する際は、以下のsvgファイルの代わりに、roadmap.htmlに記載してあるロードマップを添付すること。ただし、本ページのノードをハイライトした状態にすること。また、roadmap.htmlに記載のロードマップの0.5倍のサイズとすること。
-->



# できること

本ページでは「移動ロボット」機能の実装について解説します。

<br>

具体的には、以下の内容を実施します。

- 2輪駆動の台車パーツの印刷・組み立て
- DCモータ2つによる、前後・旋回の走行制御

!!! note 制御の仕組み
    走行は、smabo-webやスマホアプリのジョイスティックから送られる`/cmd_vel`を、smabo-esp32がモータドライバ（TB6612FNG）への指令へ変換することで実現します。
    走行機能を使う場合は、smabo-esp32の`modes.dc_drive`を有効にします。

# 構成

今回は、下図のようになります。

<!-- 以下の、smabo_sysytem_architecture.drawio.svgの代わりに、sysmap.jsをもとに作成したアーキテクチャ図を配置する。-->
<!-- 以下例のように記述するので、ハイライトするノードと矢印、およびラベルに記述する内容を確認し、アーキテクチャ図を作成してください -->
<!-- 例）コンポーネント1 -[websocket]-> コンポーネント2：データ種類1, データ種類2 -->
<!-- 今回の、具体的な構成は以下になります。 -->
<!-- smabo-brain -[websocket]-> smabo-esp32 : 速度指令 -->
<!-- smabo-esp32 -[websocket]-> smabo-brain : ホイール速度 -->



# 必要パーツ

本機能の実装に必要なパーツを以下に記載します。

| 部品名 | 商品URL | 備考 |
| --- | --- | --- |
| DCモータ（ギヤードモータ） × 2 | link | 左右の車輪用 |
| モータドライバ TB6612FNG | link | DCモータの駆動に使用します |
| タイヤ／ホイール × 2 | link | - |

# パーツの印刷

今回、新たに追加されるパーツを3Dプリンタで印刷します。

!!! note
    3Dプリンタは機種によって「印刷する際に使用するソフト」が異なるため、ここでは具体的な設定手順ではなく、ポイントのみを記載します。
<br>

以下のパーツを図の向きに設定して、印刷してください。

!!! note  印刷の際の注意点
    - パーツのつけ外しの際に、根本から折れにくくするため、凸部は横向きにして印刷
    - サポート材は必ずONにした状態で印刷

- ***.stl
    ここに画像

<br>

- ***.stl
    ここに画像

# 組み立て手順

以下動画のように、必要パーツを組み立てます。

※ 動画には、前回までに印刷したパーツも含まれます

<!--ここに、移動ロボットの組み立て動画を置いてください-->

!!! note 組み立ての際のポイント
    oooo

# 配線

!!! note ブレッドボードの+極について <!--重要なので、このNoteは特に目立つように-->
    SAD101購入時についていた、**+極のジャンプワイヤーは必ず外してください**。
    ついたままだと、**ESP32, アクチュエータが破損する**可能性があります。<!--太字を赤字にする-->
    

<br>

DCモータは、モータドライバ（TB6612FNG）を介してESP32に接続します。
smabo-esp32のデフォルト設定では、以下のピンが割り当てられています。

※ 下記表において、「接続先1」と「接続先2」は、両者が回路的に直接繋がっていることを指します。

| 接続先1 | 接続先2 | 補足 |
| --- | --- | --- |
| モータドライバ（TB6612FNG）の`pwma` | ESP32のGPIO 32 | - |
| モータドライバ（TB6612FNG）の`ain2` | ESP32のGPIO 33 | - |
| モータドライバ（TB6612FNG）の`ain1` | ESP32のGPIO 25 | - |
| モータドライバ（TB6612FNG）の`stby` | ESP32のGPIO 26 | - |
| モータドライバ（TB6612FNG）の`bin1` | ESP32のGPIO 27 | - |
| モータドライバ（TB6612FNG）の`bin2` | ESP32のGPIO 14 | - |
| モータドライバ（TB6612FNG）の`pwmb` | ESP32のGPIO 12 | - |

<br>

ESP32-DevKitCの場合の、具体的な配線図は、以下になります。

!!! note 配線の際のポイント
    oooo

# 完成系

今回作成したロボットの完成系は下図のようになります。

# 動作手順

以下手順で、動作の確認を行います。

smabo-webの「Config」タブで`dc_drive`を有効にし、「two wheel mobile robot」タブのジョイスティックを操作して、台車が前後・旋回すればOKです。

# 次回

次回は、以下ロードマップの

- [エンコーダ付移動ロボット](./encmobile.md)

について解説します。

<!--
htmlに変換する際は、以下のsvgファイルの代わりに、roadmap.htmlに記載してあるロードマップを添付すること。ただし、次回につながるノードをハイライトした状態にすること。また、roadmap.htmlに記載のロードマップの0.5倍のサイズとすること。
-->



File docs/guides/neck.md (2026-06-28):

<!--
以下は、md -> html 生成の際の指示（html生成時に直接出力する箇所ではない。以降、コメントアウトしてある箇所は、html生成時の注意事項が記載してあるものとする）

- markdownにて記載した文章は、誤字・脱字を除き、一切省略せずに、全く同じ文章でhtmlに反映すること（改行のタイミングなども含む）
    - 追記、修正した方がいい文章があった場合は、必ずユーザーに確認した上で、了承を得られた場合のみmarkdown, htmlともに修正すること
- 誤字、脱字があった場合は、markdown,html両方とも修正すること
- 表記揺れがあった場合は、どちらに統一するかユーザー側に確認したのちに、markdown, htmlともに、指定された表記に統一されるように修正すること
- 処理内容などに言及する部分に関しては、間違いがないか（コードが存在する場合は）コードの内容と照らし合わせて確認すること。その際、不整合があった場合は、ユーザー側に確認した上で了承が得られたら、markdown,htmlともに修正すること
- その他不正確な内容が含まれている場合は、ユーザー側に確認した上で了承が得られたら、markdown,htmlともに修正すること
-->

# 目次 <!-- omit in toc -->

- [ロードマップ](#ロードマップ)
- [できること](#できること)
- [構成](#構成)
- [必要パーツ](#必要パーツ)
- [パーツの印刷](#パーツの印刷)
- [組み立て手順](#組み立て手順)
- [配線](#配線)
- [完成系](#完成系)
- [動作手順](#動作手順)
- [次回](#次回)

# ロードマップ

本ページは、以下ロードマップ「首振り」のガイドページです。

また、本ページは「[smabo-esp32](./smabo-esp32.md)」のガイドを実施している前提で話を進めます。

<!--
htmlに変換する際は、以下のsvgファイルの代わりに、roadmap.htmlに記載してあるロードマップを添付すること。ただし、本ページのノードをハイライトした状態にすること。また、roadmap.htmlに記載のロードマップの0.5倍のサイズとすること。
-->



# できること

本ページでは「首振り」機能の実装について解説します。

<br>

具体的には、以下の内容を実施します。

- 首振りパーツの印刷・組み立て
- サーボモータ1つによる、首のパン（左右）方向の制御

!!! note サーボの割り当て
    首振りはサーボモータ1つで構成され、smabo-esp32のデフォルト設定では
    - `head_pan`：PCA9685 チャンネル2

    が割り当てられています。

# 構成

今回は、下図のようになります。

<!-- 以下の、smabo_sysytem_architecture.drawio.svgの代わりに、sysmap.jsをもとに作成したアーキテクチャ図を配置する。-->
<!-- 以下例のように記述するので、ハイライトするノードと矢印、およびラベルに記述する内容を確認し、アーキテクチャ図を作成してください -->
<!-- 例）コンポーネント1 -[websocket]-> コンポーネント2：データ種類1, データ種類2 -->
<!-- 今回の、具体的な構成は以下になります。 -->
<!-- smabo-brain -[websocket]-> smabo-esp32 : サーボ制御 -->



# 必要パーツ

本機能の実装に必要なパーツを以下に記載します。

| 部品名 | 商品URL | 備考 |
| --- | --- | --- |
| サーボモータ（SG90等） × 1 | link | 首のパン（左右）方向に使用します |

# パーツの印刷

今回、新たに追加されるパーツを3Dプリンタで印刷します。

!!! note
    3Dプリンタは機種によって「印刷する際に使用するソフト」が異なるため、ここでは具体的な設定手順ではなく、ポイントのみを記載します。

<br>

以下のパーツを図の向きに設定して、印刷してください。

!!! note  印刷の際の注意点
    - パーツのつけ外しの際に、根本から折れにくくするため、凸部は横向きにして印刷
    - サポート材は必ずONにした状態で印刷

- ***.stl
    ここに画像

<br>

- ***.stl
    ここに画像

# 組み立て手順

以下動画のように、必要パーツを組み立てます。

※ 動画には、前回までに印刷したパーツも含まれます

<!--ここに、首振りの組み立て動画を置いてください-->

!!! note 組み立ての際のポイント
    oooo

# 配線

!!! note ブレッドボードの+極について <!--重要なので、このNoteは特に目立つように-->
    SAD101購入時についていた、**+極のジャンプワイヤーは必ず外してください**。
    ついたままだと、**ESP32, アクチュエータが破損する**可能性があります。<!--太字を赤字にする-->
    

<br>

サーボモータは、PCA9685の各チャンネルに接続します。

※ 下記表において、「接続先1」と「接続先2」は、両者が回路的に直接繋がっていることを指します。

| 接続先1 | 接続先2 | 補足 |
| --- | --- | --- |
| `head_pan`のサーボ | PCA9685のチャンネル2 | - |

<br>

ESP32-DevKitCの場合の、具体的な配線図は、以下になります。

!!! note 配線の際のポイント
    oooo

# 完成系

今回作成したロボットの完成系は下図のようになります。

# 動作手順

以下手順で、動作の確認を行います。

smabo-webの「Servo」タブから、`head_pan`のスライダーを動かし、首が左右に振れればOKです。

# 次回

本ページはロードマップ上の終着点のひとつです。

他の機能も実装する場合は、ロードマップから次のページへ進んでください。



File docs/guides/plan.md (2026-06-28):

<!--
以下は、md -> html 生成の際の指示（html生成時に直接出力する箇所ではない。以降、コメントアウトしてある箇所は、html生成時の注意事項が記載してあるものとする）

- markdownにて記載した文章は、誤字・脱字を除き、一切省略せずに、全く同じ文章でhtmlに反映すること（改行のタイミングなども含む）
    - 追記、修正した方がいい文章があった場合は、必ずユーザーに確認した上で、了承を得られた場合のみmarkdown, htmlともに修正すること
- 誤字、脱字があった場合は、markdown,html両方とも修正すること
- 表記揺れがあった場合は、どちらに統一するかユーザー側に確認したのちに、markdown, htmlともに、指定された表記に統一されるように修正すること
- 処理内容などに言及する部分に関しては、間違いがないか（コードが存在する場合は）コードの内容と照らし合わせて確認すること。その際、不整合があった場合は、ユーザー側に確認した上で了承が得られたら、markdown,htmlともに修正すること
- その他不正確な内容が含まれている場合は、ユーザー側に確認した上で了承が得られたら、markdown,htmlともに修正すること
-->

# 目次 <!-- omit in toc -->

- [ロードマップ](#ロードマップ)
- [できること](#できること)
- [構成](#構成)
- [動作計画とは](#動作計画とは)
- [動作手順](#動作手順)
- [次回](#次回)

# ロードマップ

本ページは、以下ロードマップ「動作計画」のガイドページです。

また、本ページは「[ロボットアーム](./arm.md)」と「[brain-ros](./brainros.md)」のガイドを実施している前提で話を進めます。

<!--
htmlに変換する際は、以下のsvgファイルの代わりに、roadmap.htmlに記載してあるロードマップを添付すること。ただし、本ページのノードをハイライトした状態にすること。また、roadmap.htmlに記載のロードマップの0.5倍のサイズとすること。
-->



# できること

本ページでは「動作計画」機能の実装について解説します。

<br>

具体的には、以下の内容を実施します。

- ロボットアームの目標姿勢を指定しての動作計画・制御

# 構成

今回は、下図のようになります。

<!-- 以下の、smabo_sysytem_architecture.drawio.svgの代わりに、sysmap.jsをもとに作成したアーキテクチャ図を配置する。-->
<!-- 以下例のように記述するので、ハイライトするノードと矢印、およびラベルに記述する内容を確認し、アーキテクチャ図を作成してください -->
<!-- 例）コンポーネント1 -[websocket]-> コンポーネント2：データ種類1, データ種類2 -->
<!-- 今回の、具体的な構成は以下になります。 -->
<!-- smabo-brain -[websocket]-> smabo-esp32 : 速度指令, サーボ制御 -->
<!-- smabo-esp32 -[websocket]-> smabo-brain : ホイール速度, LiDAR -->



# 動作計画とは

動作計画は、ロボットアームについて

- 目標とする手先の位置・姿勢から、各関節の角度を求める
- 障害物や可動範囲を考慮した、関節の動かし方を計算する

を行う機能です。

<br>

smaboでは、smabo-esp32が公開する`/joint_states`をもとに、ROS 2の動作計画フレームワーク（MoveIt2）を用いて実現します。

!!! note
    具体的な手順は oooo

# 動作手順

以下手順で、動作の確認を行います。

oooo

# 次回

本ページはロードマップ上の終着点のひとつです。

他の機能も実装する場合は、ロードマップから次のページへ進んでください。



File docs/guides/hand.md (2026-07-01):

<!--
以下は、md -> html 生成の際の指示（html生成時に直接出力する箇所ではない。以降、コメントアウトしてある箇所は、html生成時の注意事項が記載してあるものとする）

- markdownにて記載した文章は、誤字・脱字を除き、一切省略せずに、全く同じ文章でhtmlに反映すること（改行のタイミングなども含む）
    - 追記、修正した方がいい文章があった場合は、必ずユーザーに確認した上で、了承を得られた場合のみmarkdown, htmlともに修正すること
- 誤字、脱字があった場合は、markdown,html両方とも修正すること
- 表記揺れがあった場合は、どちらに統一するかユーザー側に確認したのちに、markdown, htmlともに、指定された表記に統一されるように修正すること
- 処理内容などに言及する部分に関しては、間違いがないか（コードが存在する場合は）コードの内容と照らし合わせて確認すること。その際、不整合があった場合は、ユーザー側に確認した上で了承が得られたら、markdown,htmlともに修正すること
- その他不正確な内容が含まれている場合は、ユーザー側に確認した上で了承が得られたら、markdown,htmlともに修正すること
-->

# 目次 <!-- omit in toc -->

- [ロードマップ](#ロードマップ)
- [概要](#概要)
- [必要パーツ](#必要パーツ)
- [パーツの印刷](#パーツの印刷)
- [組み立て手順](#組み立て手順)
- [配線](#配線)
- [完成系](#完成系)
- [動作手順](#動作手順)
  - [起動手順](#起動手順)
  - [サーボ設定](#サーボ設定)
  - [コントローラー制御](#コントローラー制御)
  - [ランダム制御](#ランダム制御)
- [次回](#次回)

# ロードマップ

本ページは、以下ロードマップ「ハンド」のガイドページです。

また、本ページは「[smabo-esp32](./smabo-esp32.md)」のガイドを実施している前提で話を進めます。

<!--
htmlに変換する際は、以下のsvgファイルの代わりに、roadmap.jsに記載してあるロードマップを添付すること。ただし、本ページのノードをハイライトした状態にすること。また、roadmap.jsに記載のロードマップの0.5倍のサイズとすること。
-->



# 概要

本ページでは「ハンド機能」について解説します。



<br>

具体的には、以下の内容を実施します。
- ハンドのコントローラー制御
- ハンドのランダム制御

<!-- 以下の、smabo_sysytem_architecture.drawio.svgの代わりに、sysmap.jsをもとに作成したアーキテクチャ図を配置する。-->

<!-- 以下例のように記述するので、ハイライトするノードと矢印、およびラベルに記述する内容を確認し、アーキテクチャ図を作成してください -->
<!-- 例）コンポーネント1 -[websocket]-> コンポーネント2：データ種類1, データ種類2 -->
<!-- 上記の場合、-->
<!-- 1. コンポーネント1、コンポーネント2をハイライト>
<!-- 2. コンポーネント1 -> コンポーネント2方向の、websocketにあたる矢印をハイライト-->
<!-- 3. 矢印には、「データ種類1、データ種類2」とラベルを記述。ここで、読点ごとに改行すること（読点はラベルには含まない）>
<!-- 4. ラベルの行数が増えると、ラベルがノードや矢印通しで重なる可能性があるので、重なっていないことを確認すること-->

<!-- 今回の、具体的な構成は以下になります。 -->
<!-- smabo-web-[websocket]->smabo-brain：サーボ制御値 -->
<!-- smabo-brain-[websocket]->smabo-esp32：サーボ制御値 -->
<!-- smabo-web-[REST API]->smabo-esp32：esp32設定変更 -->



# 必要パーツ

本機能の実装に必要なパーツを以下に記載します。

| 部品名 | 商品URL | 備考 |
| --- | --- | --- |
| ESP32-DevKitC | [link](https://www.amazon.co.jp/ESP32-DevKitC-Bluetooth-機能マイクロコントローラー-TYPE-C-デュアルコアボード/dp/B0GTY64KDC/ref=asc_df_B0GTY64KDC?mcid=350a4550c70e3d30953041512ffe110a&tag=jpgo-22&linkCode=df0&hvadid=792079627413&hvpos=&hvnetw=g&hvrand=17366440597157412973&hvpone=&hvptwo=&hvqmt=&hvdev=c&hvdvcmdl=&hvlocint=&hvlocphy=9199153&hvtargid=pla-2484301629565&hvocijid=17366440597157412973-B0GTY64KDC-&hvexpln=0&th=1) | 互換品でも可 |
| ブレッドボード（SAD101）<br> | [link](https://www.amazon.co.jp/サンハヤト-ニューブレッドボード-SAD-101/dp/B00DSKCS68?th=1) | 一般的なブレッドボードは5穴ですが、こちらは6穴になっています。<br>6穴でないとESP32のサイズ的に横幅が足りないので注意してください |
| ジャンプワイヤー | [link](https://www.amazon.co.jp/ELEGOO-120pcs%E5%A4%9A%E8%89%B2%E3%83%87%E3%83%A5%E3%83%9D%E3%83%B3%E3%83%AF%E3%82%A4%E3%83%A4%E3%83%BC%E3%80%81arduino%E7%94%A8%E3%83%AF%E3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) | - |
| 電池ボックス（単3×4本、電池スナップ対応） | [link](https://www.amazon.co.jp/dp/B011IJQ4DI?ref_=ppx_hzsearch_conn_dt_b_fed_asin_title_3) | 電池スナップ対応の方が、取り回しが良いのでお勧めです。 |
| 電池スナップ（電池ボックス用） | [link](https://www.monotaro.com/p/6866/1105/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) | コネクタピン付きの方が、ブレッドボードに差しやすくて、抜けにくいのでお勧めです。 |
| 充電式単三電池 × 4 | [link](https://www.amazon.co.jp/Amazon%E3%83%99%E3%83%BC%E3%82%B7%E3%83%83%E3%82%AF-AmazonBasics-HR-3UTG-AMZN-%E5%85%85%E9%9B%BB%E5%BC%8F%E3%83%8B%E3%83%83%E3%82%B1%E3%83%A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) | 充電式の方がおすすめです。 |
| 電池充電器 | [link](https://www.amazon.co.jp/%E3%80%90Amazon-co-jp%E9%99%90%E5%AE%9A%E3%80%91%E3%83%91%E3%83%8A%E3%82%BD%E3%83%8B%E3%83%83%E3%82%AF-%E6%80%A5%E9%80%9F%E5%85%85%E9%9B%BB%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) | - |
| サーボモータドライバ PCA9685 | [link](https://www.amazon.co.jp/HiLetgo-PCA9685-16%E3%83%81%E3%83%A3%E3%83%B3%E3%83%8D%E3%83%AB-12-%E3%83%93%E3%83%83%E3%83%88-Arduino%E3%81%AB%E5%AF%BE%E5%BF%9C/dp/B01D1D0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) | 互換品でも可 |
| SG90 × 2 | [link](https://akizukidenshi.com/catalog/g/gM-08761/) | 互換品でも良いですが、ホーンのサイズが純正と異なる場合は、パーツにうまくはまりません。<br>そのため、ホーンを削るか、3Dモデルの修正が発生する可能性があります。 |

# パーツの印刷

今回、新たに追加されるパーツを3Dプリンタで印刷します。

!!! note
    3Dプリンタは機種によって「印刷する際に使用するソフト」が異なるため、ここでは具体的な設定手順ではなく、ポイントのみを記載します。

<br>

以下のパーツを図の向きに設定して、印刷してください。

!!! note  印刷の際の注意点
    - パーツのつけ外しの際に、根本から折れにくくするため、凸部は横向きにして印刷
    - サポート材は必ずONにした状態で印刷

- smabo-hardware/stl/hand/sg90/sg90_plate_1.stl × 2
    左右で同じパーツを使用するため、2つ印刷します
    

<br>

- smabo-hardware/stl/hand/sg90/sg90_plate_2.stl × 2
    左右で同じパーツを使用するため、2つ印刷します
    

<br>

- smabo-hardware/stl/hand/sg90/sg90_base.stl × 2
    左右で同じパーツを使用するため、2つ印刷します
    

<br>

- smabo-hardware/stl/hand/sg90/arm_hand.stl × 2
    左右で同じパーツを使用するため、2つ印刷します
    

# 組み立て手順

以下動画のように、必要パーツを組み立てます。

※ 動画には、前回までに印刷したパーツも含まれます

<!--ここに、smabo-smartphone-robot.github.io/docs/assembly_movie/hand.htmlの組み立て動画を置いてください-->

!!! note 組み立ての際のポイント
    組み立て動画では、SG90の取り付け手順は分からないため、以下に記載します。
    <br>

    最初に、下図のように「sg90_plate_1」と「sg90_plate_2」でsg90を固定し、ボディに取り付けます。
    
    

    <br>

    そして、sg90_baseを上から被せてホーンをはめ込みます（工具不要でも組み立て可能ですが、SG90に付属のネジでホーンとサーボを固定してもOKです）。
    

    <br>

    最後に、arm_handを取り付ければ完成です。
    

# 配線

下記表の内容に従って、配線します。

※ 下記表において、「接続先1」と「接続先2」は、両者が回路的に直接繋がっていることを指します。

| 接続先1 | 接続先2 | 補足 |
| --- | --- | --- |
| 乾電池バッテリーボックスの+極 | ブレッドボードの+極の**右側**<!--太字はhtmlにする際は赤色に--> | 以降、右側を6V電圧として扱うため注意 |
| 乾電池バッテリーボックスの-極 | ブレッドボードの-極 | - |
| ESP32の5V電源 | ブレッドボードの+極の**左側**<!--太字はhtmlにする際は赤文字に--> | 以降、左側を5V電圧として扱うため注意 |
| ESP32のGND | ブレッドボードの-極 | - |
| PCA9685のV++ | ブレッドボードの＋極の**右側** | - |
| PCA9685のVCC | ブレッドボードの＋極の**左側** | - |
| PCA9685のSDA | config.jsonの`i2c/sda`に設定されているピン | - |
| PCA9685のSCL | config.jsonの`i2c/scl`に設定されているピン | - |
| PCA9685のGND | ブレッドボードの-極 | - |

<br>

ESP32-DevKitCの場合の配線図は、以下になります。

※ デフォルト設定の場合、左腕のサーボをchannel=0, 右腕のサーボをchannel=1に接続してください。



!!! note 配線の際のポイント
    SG90のケーブルは、smabo背面右下の隙間から通す形でPCA9685に接続してください

# 完成系

今回作成したロボットの完成系は下図のようになります。



# 動作手順

## 起動手順

<!--
起動・接続手順は共通ページ「startup.md（startup.html）」に集約しているため、各ページでは直書きせず、必要な手順は html 側のリンクの data-steps 属性で指定する（ページにより項目を増減する）。
htmlに変換する際、「起動手順」へのリンク（startup.html）はクリックでポップアップ（モーダル）表示される。docs.js が a[href$="startup.html"] を捕捉して startup.html の .doc-content をモーダルに描画する。
ポップアップでは、リンクの data-steps 属性（startup.html の各 h2 の id をカンマ区切りで列挙）に挙げた手順だけを表示する。表示対象（data-steps）はこのコメントに記載し、html 側のリンクに同じ値を付与すること。例:
<a href="startup.html" data-steps="smabo-brainの起動,smabo-webの起動">こちらの起動手順</a>
（JS 無効時は data-steps が無視され、通常のページ遷移になる）
-->

<!--今回、起動手順に必要なのは以下のステップになるため、そのステップのみを含むようにしてください。-->
<!-- smabo-brainの起動 -->
<!-- smabo-webの起動 -->
<!-- smabo-brain <-> smabo-webの接続 -->
<!-- smabo-brain <-> esp32の接続 -->
<!-- smabo-web <-> esp32の接続 -->

「[こちらの起動手順](./startup.md)」の内容を実行してください。

## サーボ設定

smabo-webの「Config」タブのModes/servosにて、各サーボの設定を変更可能です。

最初に、「ハンドの左右のサーボモータは反対方向についている」ため、回転方向を合わせるために、right_handのみinverseを有効にします。



<br>

次に、left_hand, right_handを有効化します。



## コントローラー制御

コントローラー制御の手順を説明します。

modeを「manual」に設定してください。



<br>

「Servo」タブで各サーボの角度を変更すると、それに合わせて左右の腕が動作します。



## ランダム制御

ランダム制御の手順を説明します。

modeを「random」、groupを「hands」に設定してください。 



!!! note random_group
    同じrandom_groupに設定されたサーボモーターは、同じタイミングでランダムに動作します。

    <br>

    逆に、左右のハンドを異なるタイミングでランダムに動かしたい場合は、left_hand, right_handそれぞれが別のrandom_groupに属するように設定してください。

    <br>

    なお、新規のrandom_groupは「Add random Group」をクリックすると、追加できます。

    

<br>

しばらく待つと、ランダムなタイミングで左右のハンドが動作することが確認できます。



# 次回

本ページは、ロードマップの終端の1つです。

<br>

smaboには、他にも様々な機能があります。  

他にも試したい機能がある場合は、ロードマップからお好きなページをご覧ください。

<!--
htmlに変換する際は、以下のsvgファイルの代わりに、roadmap.jsに記載してあるロードマップを添付すること。ただし、次回につながるノードをハイライトした状態にすること。また、roadmap.jsに記載のロードマップの0.5倍のサイズとすること。
-->



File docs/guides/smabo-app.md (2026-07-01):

<!--
以下は、md -> html 生成の際の指示（html生成時に直接出力する箇所ではない。以降、コメントアウトしてある箇所は、html生成時の注意事項が記載してあるものとする）

- markdownにて記載した文章は、誤字・脱字を除き、一切省略せずに、全く同じ文章でhtmlに反映すること（改行のタイミングなども含む）
    - 追記、修正した方がいい文章があった場合は、必ずユーザーに確認した上で、了承を得られた場合のみmarkdown, htmlともに修正すること
- 誤字、脱字があった場合は、markdown,html両方とも修正すること
- 表記揺れがあった場合は、どちらに統一するかユーザー側に確認したのちに、markdown, htmlともに、指定された表記に統一されるように修正すること
- 処理内容などに言及する部分に関しては、間違いがないか（コードが存在する場合は）コードの内容と照らし合わせて確認すること。その際、不整合があった場合は、ユーザー側に確認した上で了承が得られたら、markdown,htmlともに修正すること
- その他不正確な内容が含まれている場合は、ユーザー側に確認した上で了承が得られたら、markdown,htmlともに修正すること
-->

# 目次 <!-- omit in toc -->

- [ロードマップ](#ロードマップ)
- [概要](#概要)
- [必要パーツ](#必要パーツ)
  - [smabo-appのインストール](#smabo-appのインストール)
- [動作手順](#動作手順)
  - [起動手順](#起動手順)
- [次回](#次回)

# ロードマップ

本ページは、以下ロードマップ「smabo-app」のガイドページです。

また、本ページは「[smabo-web](./smabo-web.md)」のガイドを実施している前提で話を進めます。

<!--
htmlに変換する際は、以下のsvgファイルの代わりに、roadmap.htmlに記載してあるロードマップを添付すること。ただし、本ページのノードをハイライトした状態にすること。また、roadmap.htmlに記載のロードマップの0.5倍のサイズとすること。
-->



# 概要

本ページでは「smabo-app」のセットアップ手順について解説します。



smabo-appはsmaboの中で

- smaboの顔
- smaboのセンサー（スマホのセンサーを使用）

の役割を担います。

<!-- 以下の、smabo_sysytem_architecture.drawio.svgの代わりに、sysmap.jsをもとに作成したアーキテクチャ図を配置する。-->
<!-- 以下例のように記述するので、ハイライトするノードと矢印、およびラベルに記述する内容を確認し、アーキテクチャ図を作成してください -->
<!-- 例）コンポーネント1 -[websocket]-> コンポーネント2：データ種類1, データ種類2 -->
<!-- 上記の場合、-->
<!-- 1. コンポーネント1、コンポーネント2をハイライト>
<!-- 2. コンポーネント1 -> コンポーネント2方向の、websocketにあたる矢印をハイライト-->
<!-- 3. 矢印には、「データ種類1、データ種類2」とラベルを記述。ここで、読点ごとに改行すること（読点はラベルには含まない）>
<!-- 4. ラベルの行数が増えると、ラベルがノードや矢印通しで重なる可能性があるので、重なっていないことを確認すること-->
<!-- 今回は、セットアップだけなのでsmabo-appをハイライトするだけ-->



# 必要パーツ

本機能の実装に必要なパーツを以下に記載します。

| 部品名 | 商品URL | 備考 |
| --- | --- | --- |
| スマートフォン | - | お手持ちのスマートフォン |

## smabo-appのインストール

スマホにsmabo-appをインストールします。

なお、ここではandroidの手順のみを記載します。

!!! note
    IOSの場合、flutterのインストールなどが必要になり、少し手順が多くなるため、詳しくは[smabo-appのリポジトリ](https://github.com/smabo-smartphone-robot/smabo-app)のREADMEを確認してください。

    また、IOSの場合、アプリのインストールに、mac OSのPCが必要です。

スマホから[smabo-appのReleaseページ](https://github.com/smabo-smartphone-robot/smabo-app/releases)にアクセスします。

いくつかあるバージョンの中で、一番最新バージョンのapkファイルをダウンロードしてください。

ダウンロードしたapkファイルを実行するとsmabo-appがインストールされます。

# 動作手順

## 起動手順

<!--htmlに変換する際は、startup.md の中で、「smabo-brainの起動」「smabo-webの起動」「smabo-brain <-> smabo-webの接続」「smabo-appの接続」のみをフィルタしたものを表示すること-->

<!--
htmlに変換する際、「起動手順」へのリンク（startup.html）はクリックでポップアップ（モーダル）表示される。docs.js が a[href$="startup.html"] を捕捉して startup.html の .doc-content をモーダルに描画する。
ポップアップでは、リンクの data-steps 属性（startup.html の各 h2 の id をカンマ区切りで列挙）に挙げた手順だけを表示する。表示対象（data-steps）はこのページでは以下:
<a href="startup.html" data-steps="smabo-brainの起動,smabo-webの起動,smabo-brain---smabo-webの接続,smabo-appの接続">こちらの起動手順</a>
（JS 無効時は data-steps が無視され、通常のページ遷移になる）
-->

「[こちらの起動手順](./startup.md)」の内容を実行してください。

<br>

各種プログラムの起動、通信が確認できればOKです。

# 次回

次回は、以下ロードマップの

- [smaboの顔](./smabo_face.md)
- [スマホのセンサー](./smabo_sensors.md)
- [音声処理](./audioproc.md)
- [画像処理](./imgproc.md)
- [ベースパーツの作成](./base.md)

について解説します。

<!--
htmlに変換する際は、以下のsvgファイルの代わりに、roadmap.htmlに記載してあるロードマップを添付すること。ただし、次回につながるノードをハイライトした状態にすること。また、roadmap.htmlに記載のロードマップの0.5倍のサイズとすること。
-->



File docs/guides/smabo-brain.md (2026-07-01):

<!--
以下は、md -> html 生成の際の指示（html生成時に直接出力する箇所ではない。以降、コメントアウトしてある箇所は、html生成時の注意事項が記載してあるものとする）

- markdownにて記載した文章は、誤字・脱字を除き、一切省略せずに、全く同じ文章でhtmlに反映すること（改行のタイミングなども含む）
    - 追記、修正した方がいい文章があった場合は、必ずユーザーに確認した上で、了承を得られた場合のみmarkdown, htmlともに修正すること
- 誤字、脱字があった場合は、markdown,html両方とも修正すること
- 表記揺れがあった場合は、どちらに統一するかユーザー側に確認したのちに、markdown, htmlともに、指定された表記に統一されるように修正すること
- 処理内容などに言及する部分に関しては、間違いがないか（コードが存在する場合は）コードの内容と照らし合わせて確認すること。その際、不整合があった場合は、ユーザー側に確認した上で了承が得られたら、markdown,htmlともに修正すること
- その他不正確な内容が含まれている場合は、ユーザー側に確認した上で了承が得られたら、markdown,htmlともに修正すること
-->

# 目次 <!-- omit in toc -->

- [ロードマップ](#ロードマップ)
- [概要](#概要)
- [セットアップ先（PC or SBC）](#セットアップ先pc-or-sbc)
- [必要パーツ](#必要パーツ)
- [smabo-brainのセットアップ](#smabo-brainのセットアップ)
  - [VSCodeのインストール](#vscodeのインストール)
  - [ターミナルの使い方（Linux, macの場合）](#ターミナルの使い方linux-macの場合)
  - [ターミナルの使い方（Windows）](#ターミナルの使い方windows)
    - [WSLのインストール](#wslのインストール)
    - [mirroredモードの有効化](#mirroredモードの有効化)
    - [拡張機能のインストール](#拡張機能のインストール)
    - [WSLの中に入る](#wslの中に入る)
  - [smabo-brainのクローン](#smabo-brainのクローン)
  - [パッケージのインストール](#パッケージのインストール)
- [動作手順](#動作手順)
  - [起動手順](#起動手順)
- [SBC=ラズパイ（4 or 5）の場合](#sbcラズパイ4-or-5の場合)
  - [パーツの印刷](#パーツの印刷)
  - [組み立て手順](#組み立て手順)
- [次回](#次回)

# ロードマップ

本ページは、以下ロードマップ「smabo-brain」のガイドページです。

<!--
htmlに変換する際は、以下のsvgファイルの代わりに、roadmap.htmlに記載してあるロードマップを添付すること。ただし、本ページのノードをハイライトした状態にすること。また、roadmap.htmlに記載のロードマップの0.5倍のサイズとすること。
-->



# 概要

本ページでは「smabo-brain」のセットアップ手順について解説します。

smabo-brainはsmaboの中で

- 各コンポーネントを中継するハブ
- 画像処理やAIなどの高度な処理の実行

の役割を担います。

<!-- 以下の、smabo_sysytem_architecture.drawio.svgの代わりに、sysmap.jsをもとに作成したアーキテクチャ図を配置する。-->
<!-- 以下例のように記述するので、ハイライトするノードと矢印、およびラベルに記述する内容を確認し、アーキテクチャ図を作成してください -->
<!-- 例）コンポーネント1 -[websocket]-> コンポーネント2：データ種類1, データ種類2 -->
<!-- 上記の場合、-->
<!-- 1. コンポーネント1、コンポーネント2をハイライト>
<!-- 2. コンポーネント1 -> コンポーネント2方向の、websocketにあたる矢印をハイライト-->
<!-- 3. 矢印には、「データ種類1、データ種類2」とラベルを記述。ここで、読点ごとに改行すること（読点はラベルには含まない）>
<!-- 4. ラベルの行数が増えると、ラベルがノードや矢印通しで重なる可能性があるので、重なっていないことを確認すること-->

<!-- 今回の、具体的な構成は以下になります。 -->
<!-- 今回はセットアップだけなのでsmabo-brainをハイライトするだけ-->


# セットアップ先（PC or SBC）

smabo-brainのセットアップ先には、以下の2パターンがあります。
- 外部PC
  - 「smaboとは別に用意されたPC」にsmabo-brainをセットアップ
- SBC(Single Board Computer)
  - smaboにSBCを取り付け、そのSBCにsmabo-brainをセットアップ

<br>

<br>

smabo-brain自体のセットアップ手順は同じですが、SBCの場合は
- SBC取り付け用パーツの印刷
- SBCのsmaboへの取り付け

が追加で必要になります。

そのため、最初は「外部PCへのセットアップ」をおすすめします。

!!! note 対応SBCについて
    現状、「取り付けパーツ」が用意されているSBCは以下になります。
    - ラズパイ（4 or 5）
    
    上記以外のSBCを取り付けたい場合は「取り付けパーツの3Dモデル」をCADなどで自作する必要があります。

<br>

以降では、「外部PC、SBCで共通の手順」について解説した後、「SBC固有の手順」を解説します。

# 必要パーツ

本機能の実装に必要なパーツを以下に記載します。

| 部品名 | 商品URL | 備考 |
| --- | --- | --- |
| 【任意】Raspberry Pi4 or 5 | - | SBCを使用する場合のみ |

# smabo-brainのセットアップ

ここからは、smabo-brainのセットアップ手順について解説します。

なお、ここからは「ターミナル」を使ったコマンド入力が発生します。

!!! note ターミナル
    ターミナルとは、キーボードによる入力だけでパソコンを操作する画面（CUI）のことを言います。

    一般に、システム開発ではターミナルを使って、コマンドなどを実行することが多いです。

## VSCodeのインストール

最初に、ターミナルを使用する環境を構築します。

<br>

今回は、Visual Studio Code（VSCode）を使用します（VSCodeはコードエディタの一つです）。

<br>

以下サイトから、ご自身のPCのOSにあったインストーラをダウンロードしてください。

https://code.visualstudio.com

<br>

ダウンロードが完了したら、VSCodeをインストール、起動します。

## ターミナルの使い方（Linux, macの場合）

画面下部の「TREMINAL」というタブがターミナルになります。



以降、コマンドの記載がある際は、こちらにのタブにて、コマンドを入力してください。

## ターミナルの使い方（Windows）

Windows PCを使用する場合は、WSLをインストールしてください。

<br>

WSL(Windows for Linux)は、
- WindowsでLinuxの環境を使用できるシステム

です。

ロボット開発ではLinuxを使用できた方が後々便利なことが多いので、以降はWSL上で作業を進めます。

<br>

### WSLのインストール

WSLのインストール手順については、以下の記事を参考にしてください。

[WSL2 のインストールとアンインストール](https://qiita.com/zakoken/items/61141df6aeae9e3f8e36)

### mirroredモードの有効化

WSL2のデフォルト設定では、外部環境との通信ができません。

以降で、スマホやESP32といった外部機器との通信が必要になるため、以下の記事を参考にmirroredモードに設定してください。

[wsl2 mirroredネットワーク、WindowsとLinuxの良いとこどり！](https://qiita.com/shansukey/items/008669cdf392315a656f)

### 拡張機能のインストール

WSLのインストールが完了したら、VScodeにて以下の拡張機能をインストールしてください。
- WSL



### WSLの中に入る

拡張機能のインストールが完了したら、

1. 「><」マークをクリック
2. 「Connected to WSL」をクリックしてください。



<br>

画面左下に「WSL：Ubuntu」と表示されていればOKです。ここで、画面下部の「TERMINAL」というタブがターミナルになります。



以降、コマンドの記載がある際は、こちらにコマンドを入力してください。

## smabo-brainのクローン

以下コマンドでsmabo-brainリポジトリをクローンします。

```bash
# ホームディレクトリへ移動
cd ~ 
```

```bash
# smabo-brainリポジトリのクローン
git clone https://github.com/smabo-smartphone-robot/smabo-brain
```

## パッケージのインストール

各種プログラムの実行に必要なパッケージをインストールします。

```bash
cd ~/smabo-brain
```

```bash
pip3 install -r requirements.txt
```

# 動作手順

## 起動手順

<!--htmlに変換する際は、startup.md の中で、「smabo-brainの起動」のみをフィルタしたものを表示すること-->

<!--
htmlに変換する際、「起動手順」へのリンク（startup.html）はクリックでポップアップ（モーダル）表示される。docs.js が a[href$="startup.html"] を捕捉して startup.html の .doc-content をモーダルに描画する。
ポップアップでは、リンクの data-steps 属性（startup.html の各 h2 の id をカンマ区切りで列挙）に挙げた手順だけを表示する。表示対象（data-steps）はこのページでは以下:
<a href="startup.html" data-steps="smabo-brainの起動">こちらの起動手順</a>
（JS 無効時は data-steps が無視され、通常のページ遷移になる）
-->

「[こちらの起動手順](./startup.md)」の内容を実行してください。

<br>

エラーが発生せずに、起動が完了すればOKです。

<br>

ここまでで、「SBC、PCで共通の設定」は完了です。
また、PCにセットアップした方は本ページの実施内容は以上になります。

<br>

以降は、「SBCをsmabo本体に取り付ける」手順について解説します。

# SBC=ラズパイ（4 or 5）の場合

SBCにラズパイを使用する場合の、パーツの印刷、取り付け手順を解説します。

## パーツの印刷

今回、新たに追加されるパーツを3Dプリンタで印刷します。

!!! note
    3Dプリンタは機種によって「印刷する際に使用するソフト」が異なるため、ここでは具体的な設定手順ではなく、ポイントのみを記載します。

<br>

以下のパーツを図の向きに設定して、印刷してください。

!!! note  印刷の際の注意点
    - パーツのつけ外しの際に、根本から折れにくくするため、凸部は横向きにして印刷
    - サポート材は必ずONにした状態で印刷

- smabo-hardware/stl/raspi/raspi_stand.stl
    

<br>

- smabo-hardware/stl/raspi/raspi_stopper1.stl
    

<br>

- smabo-hardware/stl/raspi/raspi_stopper2.stl
    

## 組み立て手順

以下動画のように、必要パーツを組み立てます。

※ 動画には、前回までに印刷したパーツも含まれます

<!--ここに、docs/assembly_movie/smabo_raspi.htmlの組み立て動画を置いてください-->

!!! note 組み立ての際のポイント
    下図のように、ラズパイを各パーツでraspi_standに固定してください。
    

# 次回

次回は、以下ロードマップの

- [smabo-web](./smabo-web.md)

について解説します。

<!--
htmlに変換する際は、以下のsvgファイルの代わりに、roadmap.htmlに記載してあるロードマップを添付すること。ただし、次回につながるノードをハイライトした状態にすること。また、roadmap.htmlに記載のロードマップの0.5倍のサイズとすること。
-->



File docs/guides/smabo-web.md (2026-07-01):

<!--
以下は、md -> html 生成の際の指示（html生成時に直接出力する箇所ではない。以降、コメントアウトしてある箇所は、html生成時の注意事項が記載してあるものとする）

- markdownにて記載した文章は、誤字・脱字を除き、一切省略せずに、全く同じ文章でhtmlに反映すること（改行のタイミングなども含む）
    - 追記、修正した方がいい文章があった場合は、必ずユーザーに確認した上で、了承を得られた場合のみmarkdown, htmlともに修正すること
- 誤字、脱字があった場合は、markdown,html両方とも修正すること
- 表記揺れがあった場合は、どちらに統一するかユーザー側に確認したのちに、markdown, htmlともに、指定された表記に統一されるように修正すること
- 処理内容などに言及する部分に関しては、間違いがないか（コードが存在する場合は）コードの内容と照らし合わせて確認すること。その際、不整合があった場合は、ユーザー側に確認した上で了承が得られたら、markdown,htmlともに修正すること
- その他不正確な内容が含まれている場合は、ユーザー側に確認した上で了承が得られたら、markdown,htmlともに修正すること
-->

# 目次 <!-- omit in toc -->

- [ロードマップ](#ロードマップ)
- [概要](#概要)
  - [smabo-webのクローン](#smabo-webのクローン)
  - [パッケージのインストール](#パッケージのインストール)
- [動作手順](#動作手順)
  - [起動手順](#起動手順)
- [次回](#次回)

# ロードマップ

本ページは、以下ロードマップ「smabo-web」のガイドページです。

また、本ページは「[smabo-brain](./smabo-brain.md)」のガイドを実施している前提で話を進めます。

<!--
htmlに変換する際は、以下のsvgファイルの代わりに、roadmap.htmlに記載してあるロードマップを添付すること。ただし、本ページのノードをハイライトした状態にすること。また、roadmap.htmlに記載のロードマップの0.5倍のサイズとすること。
-->



# 概要

本ページでは「smabo-web」のセットアップ手順について解説します。



<br>

smabo-webはsmaboの中で

- smaboの設定の変更、手動操作、センサの可視化などの補助的ツール

の役割を担います。

<!-- 以下の、smabo_sysytem_architecture.drawio.svgの代わりに、sysmap.jsをもとに作成したアーキテクチャ図を配置する。-->
<!-- 以下例のように記述するので、ハイライトするノードと矢印、およびラベルに記述する内容を確認し、アーキテクチャ図を作成してください -->
<!-- 例）コンポーネント1 -[websocket]-> コンポーネント2：データ種類1, データ種類2 -->
<!-- 上記の場合、-->
<!-- 1. コンポーネント1、コンポーネント2をハイライト>
<!-- 2. コンポーネント1 -> コンポーネント2方向の、websocketにあたる矢印をハイライト-->
<!-- 3. 矢印には、「データ種類1、データ種類2」とラベルを記述。ここで、読点ごとに改行すること（読点はラベルには含まない）>
<!-- 4. ラベルの行数が増えると、ラベルがノードや矢印通しで重なる可能性があるので、重なっていないことを確認すること-->

<!-- 今回の、具体的な構成は以下になります。 -->
<!-- 今回はセットアップするだけなので、smabo-webをハイライトするだけ -->



## smabo-webのクローン

以下コマンドでsmabo-webリポジトリをクローンします。

```bash
# ホームディレクトリへ移動
cd ~ 
```

```bash
# smabo-brainリポジトリのクローン
git clone https://github.com/smabo-smartphone-robot/smabo-web
```

## パッケージのインストール

各種プログラムの実行に必要なパッケージをインストールします。

```bash
cd ~/smabo-web
```

```bash
npm install
```

# 動作手順

## 起動手順

<!--htmlに変換する際は、startup.md の中で、「smabo-brainの起動」「smabo-webの起動」「smabo-brain <-> smabo-webの接続」のみをフィルタしたものを表示すること-->

<!--
htmlに変換する際、「起動手順」へのリンク（startup.html）はクリックでポップアップ（モーダル）表示される。docs.js が a[href$="startup.html"] を捕捉して startup.html の .doc-content をモーダルに描画する。
ポップアップでは、リンクの data-steps 属性（startup.html の各 h2 の id をカンマ区切りで列挙）に挙げた手順だけを表示する。表示対象（data-steps）はこのページでは以下:
<a href="startup.html" data-steps="smabo-brainの起動,smabo-webの起動,smabo-brain---smabo-webの接続">こちらの起動手順</a>
（JS 無効時は data-steps が無視され、通常のページ遷移になる）
-->

「[こちらの起動手順](./startup.md)」の内容を実行してください。

<br>

各種プログラムの起動、通信が確認できればOKです。

# 次回

次回は、以下ロードマップの

- [smabo-app](./smabo-app.md)

について解説します。

<!--
htmlに変換する際は、以下のsvgファイルの代わりに、roadmap.htmlに記載してあるロードマップを添付すること。ただし、次回につながるノードをハイライトした状態にすること。また、roadmap.htmlに記載のロードマップの0.5倍のサイズとすること。
-->



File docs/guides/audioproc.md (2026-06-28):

<!--
以下は、md -> html 生成の際の指示（html生成時に直接出力する箇所ではない。以降、コメントアウトしてある箇所は、html生成時の注意事項が記載してあるものとする）

- markdownにて記載した文章は、誤字・脱字を除き、一切省略せずに、全く同じ文章でhtmlに反映すること（改行のタイミングなども含む）
    - 追記、修正した方がいい文章があった場合は、必ずユーザーに確認した上で、了承を得られた場合のみmarkdown, htmlともに修正すること
- 誤字、脱字があった場合は、markdown,html両方とも修正すること
- 表記揺れがあった場合は、どちらに統一するかユーザー側に確認したのちに、markdown, htmlともに、指定された表記に統一されるように修正すること
- 処理内容などに言及する部分に関しては、間違いがないか（コードが存在する場合は）コードの内容と照らし合わせて確認すること。その際、不整合があった場合は、ユーザー側に確認した上で了承が得られたら、markdown,htmlともに修正すること
- その他不正確な内容が含まれている場合は、ユーザー側に確認した上で了承が得られたら、markdown,htmlともに修正すること
-->

# 目次 <!-- omit in toc -->

- [ロードマップ](#ロードマップ)
- [概要](#概要)
- [必要パーツ](#必要パーツ)
- [動作手順](#動作手順)
  - [起動手順](#起動手順)
  - [音声認識](#音声認識)
  - [音声発話](#音声発話)
- [次回](#次回)

# ロードマップ

本ページは、以下ロードマップ「音声処理」のガイドページです。

また、本ページは「smabo-app」のガイドを実施している前提で話を進めます。

<!--
htmlに変換する際は、以下のsvgファイルの代わりに、roadmap.htmlに記載してあるロードマップを添付すること。ただし、本ページのノードをハイライトした状態にすること。また、roadmap.htmlに記載のロードマップの0.5倍のサイズとすること。
-->



# 概要

本ページでは「音声処理機能」について解説します。

具体的には、以下の内容を実施します。
- スマホのマイクから取得した音声を、音声認識
  - 認識結果をsmabo-webに表示
- smabo-webで指定した文字列をスマホで発話

<!-- 以下の、smabo_sysytem_architecture.drawio.svgの代わりに、sysmap.jsをもとに作成したアーキテクチャ図を配置する。-->
<!-- 以下例のように記述するので、ハイライトするノードと矢印、およびラベルに記述する内容を確認し、アーキテクチャ図を作成してください -->
<!-- 例）コンポーネント1 -[websocket]-> コンポーネント2：データ種類1, データ種類2 -->
<!-- 上記の場合、-->
<!-- 1. コンポーネント1、コンポーネント2をハイライト>
<!-- 2. コンポーネント1 -> コンポーネント2方向の、websocketにあたる矢印をハイライト-->
<!-- 3. 矢印には、「データ種類1、データ種類2」とラベルを記述。ここで、読点ごとに改行すること（読点はラベルには含まない）>
<!-- 4. ラベルの行数が増えると、ラベルがノードや矢印通しで重なる可能性があるので、重なっていないことを確認すること-->
<!-- 今回の、具体的な構成は以下になります。 -->
<!-- smabo-app -[websocket]-> smabo-brain : 音声 -->
<!-- smabo-brain -[websocket]-> smabo-web : 音声認識結果 -->
<!-- smabo-web -[websocket]-> smabo-brain : 発話文字列 -->
<!-- smabo-brain -[websocket]-> smabo-app : 発話文字列 -->



# 必要パーツ

本機能の実装に必要なパーツを以下に記載します。

| 部品名 | 商品URL | 備考 |
| --- | --- | --- |
| スマートフォン | - | smabo-appをインストール済みのスマホ |

# 動作手順

## 起動手順

<!--htmlに変換する際は、startup.md の中で、「smabo-brainの起動」「smabo-webの起動」「smabo-brain <-> smabo-webの接続」「smabo-appの接続」のみをフィルタしたものを表示すること-->

<!--
htmlに変換する際、「起動手順」へのリンク（startup.html）はクリックでポップアップ（モーダル）表示される。docs.js が a[href$="startup.html"] を捕捉して startup.html の .doc-content をモーダルに描画する。
ポップアップでは、リンクの data-steps 属性（startup.html の各 h2 の id をカンマ区切りで列挙）に挙げた手順だけを表示する。表示対象（data-steps）はこのページでは以下:
<a href="startup.html" data-steps="smabo-brainの起動,smabo-webの起動,smabo-brain---smabo-webの接続,smabo-appの接続">こちらの起動手順</a>
（JS 無効時は data-steps が無視され、通常のページ遷移になる）
-->

「[こちらの起動手順](./startup.md)」の内容を実行してください。

## 音声認識

smaboに対して「smabo」と話しかけると、smaboの目が虹色に光ります（wake upワードはsmabo-appの設定画面から変更できます）。

目が虹色の状態で何か言葉を話すと、音声認識が開始されます（認識する言語は、smabo-appの設定画面から変更できます）。



<br>

目の色が戻った後に、smabo-webの「Face」タブの「Recognized speech」を確認すると、先ほど話した言葉が表示されます。



## 音声発話

smabo-webの「Face」タブの「SPEECH / SAY」で、任意の文章を入力し、「SAY」ボタンをクリックすると入力された音声がスマホから発話されます（発話する言語は、smabo-appの設定画面から変更できます）。



<br>

なお、「Bubble ON」「Speak ON」ボタンにて発話のON/OFF、吹き出しの有無を設定可能です。



# 次回

次回は、以下ロードマップの

- [ベースパーツの作成](./base.md)

について解説します。

<!--
htmlに変換する際は、以下のsvgファイルの代わりに、roadmap.htmlに記載してあるロードマップを添付すること。ただし、次回につながるノードをハイライトした状態にすること。また、roadmap.htmlに記載のロードマップの0.5倍のサイズとすること。
-->



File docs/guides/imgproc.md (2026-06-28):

<!--
以下は、md -> html 生成の際の指示（html生成時に直接出力する箇所ではない。以降、コメントアウトしてある箇所は、html生成時の注意事項が記載してあるものとする）

- markdownにて記載した文章は、誤字・脱字を除き、一切省略せずに、全く同じ文章でhtmlに反映すること（改行のタイミングなども含む）
    - 追記、修正した方がいい文章があった場合は、必ずユーザーに確認した上で、了承を得られた場合のみmarkdown, htmlともに修正すること
- 誤字、脱字があった場合は、markdown,html両方とも修正すること
- 表記揺れがあった場合は、どちらに統一するかユーザー側に確認したのちに、markdown, htmlともに、指定された表記に統一されるように修正すること
- 処理内容などに言及する部分に関しては、間違いがないか（コードが存在する場合は）コードの内容と照らし合わせて確認すること。その際、不整合があった場合は、ユーザー側に確認した上で了承が得られたら、markdown,htmlともに修正すること
- その他不正確な内容が含まれている場合は、ユーザー側に確認した上で了承が得られたら、markdown,htmlともに修正すること
-->

# 目次 <!-- omit in toc -->

- [ロードマップ](#ロードマップ)
- [概要](#概要)
- [動作手順](#動作手順)
  - [起動手順](#起動手順)
  - [画像認識](#画像認識)
  - [物体認識をもとに制御](#物体認識をもとに制御)
- [次回](#次回)

# ロードマップ

本ページは、以下ロードマップ「画像処理」のガイドページです。

また、本ページは「[smabo-brain](./smabo-brain.md)」と「[smabo-app](./smabo-app.md)」のガイドを実施している前提で話を進めます。

<!--
htmlに変換する際は、以下のsvgファイルの代わりに、roadmap.htmlに記載してあるロードマップを添付すること。ただし、本ページのノードをハイライトした状態にすること。また、roadmap.htmlに記載のロードマップの0.5倍のサイズとすること。
-->



# 概要

本ページでは「画像処理」機能の実装について解説します。

具体的には、以下の内容を実施します。
- smabo-webから画像処理の設定
  - 認識対象（色物体、ARマーカー、QRコード）の設定など
- カメラから取得した画像をもとに、対象物体を識別
  - 識別結果をsmabo-webで可視化
  - 識別結果をもとにsmaboの目を制御

<!-- 以下の、smabo_sysytem_architecture.drawio.svgの代わりに、sysmap.jsをもとに作成したアーキテクチャ図を配置する。-->
<!-- 以下例のように記述するので、ハイライトするノードと矢印、およびラベルに記述する内容を確認し、アーキテクチャ図を作成してください -->
<!-- 例）コンポーネント1 -[websocket]-> コンポーネント2：データ種類1, データ種類2 -->
<!-- 上記の場合、-->
<!-- 1. コンポーネント1、コンポーネント2をハイライト>
<!-- 2. コンポーネント1 -> コンポーネント2方向の、websocketにあたる矢印をハイライト-->
<!-- 3. 矢印には、「データ種類1、データ種類2」とラベルを記述。ここで、読点ごとに改行すること（読点はラベルには含まない）>
<!-- 4. ラベルの行数が増えると、ラベルがノードや矢印通しで重なる可能性があるので、重なっていないことを確認すること-->
<!-- 今回の、具体的な構成は以下になります。 -->
<!-- smabo-app -[webrtc]-> smabo-brain : 画像 -->
<!-- smabo-brain -[webrtc]-> smabo-web : 画像 -->
<!-- smabo-brain -[websocket]-> smabo-app：目の制御-->
<!-- smabo-web -[websocket]-> smabo-brain：画像処理設定-->
<!-- smabo-brain -[websocket]-> smabo-web：画像処理検出結果-->



# 動作手順

## 起動手順

<!--htmlに変換する際は、startup.md の中で、「smabo-brainの起動」「smabo-webの起動」「smabo-brain <-> smabo-webの接続」「smabo-appの接続」のみをフィルタしたものを表示すること-->

<!--
htmlに変換する際、「起動手順」へのリンク（startup.html）はクリックでポップアップ（モーダル）表示される。docs.js が a[href$="startup.html"] を捕捉して startup.html の .doc-content をモーダルに描画する。
ポップアップでは、リンクの data-steps 属性（startup.html の各 h2 の id をカンマ区切りで列挙）に挙げた手順だけを表示する。表示対象（data-steps）はこのページでは以下:
<a href="startup.html" data-steps="smabo-brainの起動,smabo-webの起動,smabo-brain---smabo-webの接続,smabo-appの接続">こちらの起動手順</a>
（JS 無効時は data-steps が無視され、通常のページ遷移になる）
-->

「[こちらの起動手順](./startup.md)」の内容を実行してください。

## 画像認識

smabo-webの「Vision」タブにて画像認識に関する設定が可能で、「Detection」の「enabled」を有効化することで、画像認識機能を有効化できます。



<br>

画像認識はいくつかの種類が用意してあり、「Mode」を変更することで、以下の物体を認識可能です。
- ARマーカー
- 指定した色の物体
- 顔認識
- QRコード



<br>

なお、Min sizeを設定することで
- 画像内で認識対象とする物体の最小サイズ（このサイズ以上の物体は認識対象とする）

を設定可能です（プレビューを有効化すると、右下に最小サイズの枠が表示されます）。


 
## 物体認識をもとに制御

「BEHAVIORS」にて、認識結果をもとにした制御も可能です。

具体的には、
- 認識した中で、「一番大きい物体」の座標や画像サイズをもとに制御

します。



<br>

制御の種類としては、以下になります。
- 目の制御
  - 認識した物体を追従するようにsmaboの目が動作
- サーボの制御
  - 認識した物体に追従するようにサーボが動作
  - 左右方向、上下方向それぞれにサーボを設定可能
  - 詳細は「[顔振り](./neck.md)」にて解説
- 二輪駆動ロボットの制御
  - 認識した物体を追従するようにロボットを制御
  - 物体のサイズが、target sizeに設定されたサイズを維持するように、ロボットが前進、後退
  - 詳細は、「[移動ロボット](./mobile.md)」にて解説

<br>

例えば、「目の制御」の場合、
- smabo-appの顔のモードを「Follow」にした状態

で、認識対象の物体をカメラの前に持ってくると、smaboの目が追従することが確認できます。



# 次回

次回は、以下ロードマップの

- [ベースパーツの作成](./base.md)

について解説します。



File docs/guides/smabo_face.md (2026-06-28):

<!--
以下は、md -> html 生成の際の指示（html生成時に直接出力する箇所ではない。以降、コメントアウトしてある箇所は、html生成時の注意事項が記載してあるものとする）

- markdownにて記載した文章は、誤字・脱字を除き、一切省略せずに、全く同じ文章でhtmlに反映すること（改行のタイミングなども含む）
    - 追記、修正した方がいい文章があった場合は、必ずユーザーに確認した上で、了承を得られた場合のみmarkdown, htmlともに修正すること
- 誤字、脱字があった場合は、markdown,html両方とも修正すること
- 表記揺れがあった場合は、どちらに統一するかユーザー側に確認したのちに、markdown, htmlともに、指定された表記に統一されるように修正すること
- 処理内容などに言及する部分に関しては、間違いがないか（コードが存在する場合は）コードの内容と照らし合わせて確認すること。その際、不整合があった場合は、ユーザー側に確認した上で了承が得られたら、markdown,htmlともに修正すること
- その他不正確な内容が含まれている場合は、ユーザー側に確認した上で了承が得られたら、markdown,htmlともに修正すること
-->

# 目次 <!-- omit in toc -->

- [ロードマップ](#ロードマップ)
- [概要](#概要)
- [必要パーツ](#必要パーツ)
- [動作手順](#動作手順)
  - [起動手順](#起動手順)
  - [smaboの顔のカスタマイズ](#smaboの顔のカスタマイズ)
  - [smaboの表情の変更](#smaboの表情の変更)
  - [smaboの目をコントローラーで動かす](#smaboの目をコントローラーで動かす)
- [次回](#次回)

# ロードマップ

本ページは、以下ロードマップ「smaboの顔」のガイドページです。

また、本ページは「smabo-app」のガイドを実施している前提で話を進めます。

<!--
htmlに変換する際は、以下のsvgファイルの代わりに、roadmap.htmlに記載してあるロードマップを添付すること。ただし、本ページのノードをハイライトした状態にすること。また、roadmap.htmlに記載のロードマップの0.5倍のサイズとすること。
-->



# 概要

本ページでは「smaboの顔機能」の使い方について解説します。

具体的には、以下の内容を実施します。

- smabo-webから、smaboの表情を変更
- smabo-webから、smaboの目をコントロール

<!-- 以下の、smabo_sysytem_architecture.drawio.svgの代わりに、sysmap.jsをもとに作成したアーキテクチャ図を配置する。-->
<!-- 以下例のように記述するので、ハイライトするノードと矢印、およびラベルに記述する内容を確認し、アーキテクチャ図を作成してください -->
<!-- 例）コンポーネント1 -[websocket]-> コンポーネント2：データ種類1, データ種類2 -->
<!-- 上記の場合、-->
<!-- 1. コンポーネント1、コンポーネント2をハイライト>
<!-- 2. コンポーネント1 -> コンポーネント2方向の、websocketにあたる矢印をハイライト-->
<!-- 3. 矢印には、「データ種類1、データ種類2」とラベルを記述。ここで、読点ごとに改行すること（読点はラベルには含まない）>
<!-- 4. ラベルの行数が増えると、ラベルがノードや矢印通しで重なる可能性があるので、重なっていないことを確認すること-->
<!-- 今回の、具体的な構成は以下になります。 -->
<!-- smabo-web -[websocket]-> smabo-brain：表情変更、目の制御-->
<!-- smabo-brain -[websocket]-> smabo-app：表情変更、目の制御-->



# 必要パーツ

本機能の実装に必要なパーツを以下に記載します。

| 部品名 | 商品URL | 備考 |
| --- | --- | --- |
| スマートフォン | - | smabo-appをインストールしたスマートフォン |

# 動作手順

## 起動手順

<!--htmlに変換する際は、startup.md の中で、「smabo-brainの起動」「smabo-webの起動」「smabo-brain <-> smabo-webの接続」「smabo-appの接続」のみをフィルタしたものを表示すること-->

<!--
htmlに変換する際、「起動手順」へのリンク（startup.html）はクリックでポップアップ（モーダル）表示される。docs.js が a[href$="startup.html"] を捕捉して startup.html の .doc-content をモーダルに描画する。
ポップアップでは、リンクの data-steps 属性（startup.html の各 h2 の id をカンマ区切りで列挙）に挙げた手順だけを表示する。表示対象（data-steps）はこのページでは以下:
<a href="startup.html" data-steps="smabo-brainの起動,smabo-webの起動,smabo-brain---smabo-webの接続,smabo-appの接続">こちらの起動手順</a>
（JS 無効時は data-steps が無視され、通常のページ遷移になる）
-->

「[こちらの起動手順](./startup.md)」の内容を実行してください。

## smaboの顔のカスタマイズ

smaboの顔は、「Face Settings」から設定を変更できます。



<br>

設定では「目の大きさ」「目の種類」「背景色の変更」などができます。



## smaboの表情の変更

smabo-webの「Face」タブの「Expression」に「Expression ID（smabo-app内のFace settingsで設定した表情のID）」を変更し、「Set」をクリックすると、smaboの目の種類が変化します。



## smaboの目をコントローラーで動かす

smaboの目はデフォルトでは、ランダムに動きますが、モードを「Follow」に変更すると、外部からの通信により自由に動かすことができます。



<br>

例えば、smabo-webの「Face」タブの「Gaze control」でコントローラを操作すると、それに合わせて目が動くことが確認できます。



# 次回

次回は、以下ロードマップの

- [ベースパーツの作成](./base.md)

について解説します。

<!--
htmlに変換する際は、以下のsvgファイルの代わりに、roadmap.htmlに記載してあるロードマップを添付すること。ただし、次回につながるノードをハイライトした状態にすること。また、roadmap.htmlに記載のロードマップの0.5倍のサイズとすること。
-->



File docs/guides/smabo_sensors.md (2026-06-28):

<!--
以下は、md -> html 生成の際の指示（html生成時に直接出力する箇所ではない。以降、コメントアウトしてある箇所は、html生成時の注意事項が記載してあるものとする）

- markdownにて記載した文章は、誤字・脱字を除き、一切省略せずに、全く同じ文章でhtmlに反映すること（改行のタイミングなども含む）
    - 追記、修正した方がいい文章があった場合は、必ずユーザーに確認した上で、了承を得られた場合のみmarkdown, htmlともに修正すること
- 誤字、脱字があった場合は、markdown,html両方とも修正すること
- 表記揺れがあった場合は、どちらに統一するかユーザー側に確認したのちに、markdown, htmlともに、指定された表記に統一されるように修正すること
- 処理内容などに言及する部分に関しては、間違いがないか（コードが存在する場合は）コードの内容と照らし合わせて確認すること。その際、不整合があった場合は、ユーザー側に確認した上で了承が得られたら、markdown,htmlともに修正すること
- その他不正確な内容が含まれている場合は、ユーザー側に確認した上で了承が得られたら、markdown,htmlともに修正すること
-->

# 目次 <!-- omit in toc -->

- [ロードマップ](#ロードマップ)
- [概要](#概要)
- [必要パーツ](#必要パーツ)
- [動作手順](#動作手順)
  - [起動手順](#起動手順)
  - [各種センサーの状態を可視化](#各種センサーの状態を可視化)
- [次回](#次回)

# ロードマップ

本ページは、以下ロードマップ「スマホのセンサー」のガイドページです。

また、本ページは「smabo-app」のガイドを実施している前提で話を進めます。

<!--
htmlに変換する際は、以下のsvgファイルの代わりに、roadmap.htmlに記載してあるロードマップを添付すること。ただし、本ページのノードをハイライトした状態にすること。また、roadmap.htmlに記載のロードマップの0.5倍のサイズとすること。
-->



# 概要

本ページでは「スマホのセンサー」機能の使い方について解説します。

具体的には、以下の内容を実施します。
- スマホから受け取ったセンサデータ（画像、IMU、GPS）をsmabo-webで可視化

<!-- 以下の、smabo_sysytem_architecture.drawio.svgの代わりに、sysmap.jsをもとに作成したアーキテクチャ図を配置する。-->
<!-- 以下例のように記述するので、ハイライトするノードと矢印、およびラベルに記述する内容を確認し、アーキテクチャ図を作成してください -->
<!-- 例）コンポーネント1 -[websocket]-> コンポーネント2：データ種類1, データ種類2 -->
<!-- 上記の場合、-->
<!-- 1. コンポーネント1、コンポーネント2をハイライト>
<!-- 2. コンポーネント1 -> コンポーネント2方向の、websocketにあたる矢印をハイライト-->
<!-- 3. 矢印には、「データ種類1、データ種類2」とラベルを記述。ここで、読点ごとに改行すること（読点はラベルには含まない）>
<!-- 4. ラベルの行数が増えると、ラベルがノードや矢印通しで重なる可能性があるので、重なっていないことを確認すること-->

<!-- 今回の、具体的な構成は以下になります。 -->
<!-- smabo-app -[webRTC]-> smabo-brain : 画像 -->
<!-- smabo-app -[websocket]-> smabo-brain : IMU, GPS -->
<!-- smabo-brain -[webRTC]-> smabo-web : 画像 -->
<!-- smabo-brain -[websocket]-> smabo-web : IMU, GPS -->



# 必要パーツ

本機能の実装に必要なパーツを以下に記載します。

| 部品名 | 商品URL | 備考 |
| --- | --- | --- |
| スマートフォン | - | smabo-appをインストール済みのスマホ |

# 動作手順

## 起動手順

<!--htmlに変換する際は、startup.md の中で、「smabo-brainの起動」「smabo-webの起動」「smabo-brain <-> smabo-webの接続」「smabo-appの接続」のみをフィルタしたものを表示すること-->

<!--
htmlに変換する際、「起動手順」へのリンク（startup.html）はクリックでポップアップ（モーダル）表示される。docs.js が a[href$="startup.html"] を捕捉して startup.html の .doc-content をモーダルに描画する。
ポップアップでは、リンクの data-steps 属性（startup.html の各 h2 の id をカンマ区切りで列挙）に挙げた手順だけを表示する。表示対象（data-steps）はこのページでは以下:
<a href="startup.html" data-steps="smabo-brainの起動,smabo-webの起動,smabo-brain---smabo-webの接続,smabo-appの接続">こちらの起動手順</a>
（JS 無効時は data-steps が無視され、通常のページ遷移になる）
-->

「[こちらの起動手順](./startup.md)」の内容を実行してください。

## 各種センサーの状態を可視化

smaboの各種センサのON/OFFは左下のボタンで設定できます。



<br>

センサをONにした状態で、smabo-webで「Sensors」タブを確認すると、各種センサの情報を可視化できます。



# 次回

次回は、以下ロードマップの

- [ベースパーツの作成](./base.md)

について解説します。

<!--
htmlに変換する際は、以下のsvgファイルの代わりに、roadmap.htmlに記載してあるロードマップを添付すること。ただし、次回につながるノードをハイライトした状態にすること。また、roadmap.htmlに記載のロードマップの0.5倍のサイズとすること。
-->



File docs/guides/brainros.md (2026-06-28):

<!--
以下は、md -> html 生成の際の指示（html生成時に直接出力する箇所ではない。以降、コメントアウトしてある箇所は、html生成時の注意事項が記載してあるものとする）

- markdownにて記載した文章は、誤字・脱字を除き、一切省略せずに、全く同じ文章でhtmlに反映すること（改行のタイミングなども含む）
    - 追記、修正した方がいい文章があった場合は、必ずユーザーに確認した上で、了承を得られた場合のみmarkdown, htmlともに修正すること
- 誤字、脱字があった場合は、markdown,html両方とも修正すること
- 表記揺れがあった場合は、どちらに統一するかユーザー側に確認したのちに、markdown, htmlともに、指定された表記に統一されるように修正すること
- 処理内容などに言及する部分に関しては、間違いがないか（コードが存在する場合は）コードの内容と照らし合わせて確認すること。その際、不整合があった場合は、ユーザー側に確認した上で了承が得られたら、markdown,htmlともに修正すること
- その他不正確な内容が含まれている場合は、ユーザー側に確認した上で了承が得られたら、markdown,htmlともに修正すること
-->

# 目次 <!-- omit in toc -->

- [ロードマップ](#ロードマップ)
- [できること](#できること)
- [構成](#構成)
- [smabo-brain-rosとは](#smabo-brain-rosとは)
  - [smabo-brain-rosのクローン](#smabo-brain-rosのクローン)
  - [ビルド](#ビルド)
- [動作手順](#動作手順)
- [次回](#次回)

# ロードマップ

本ページは、以下ロードマップ「brain-ros」のガイドページです。

また、本ページは「[smabo-brain](./smabo-brain.md)」のガイドを実施している前提で話を進めます。

<!--
htmlに変換する際は、以下のsvgファイルの代わりに、roadmap.htmlに記載してあるロードマップを添付すること。ただし、本ページのノードをハイライトした状態にすること。また、roadmap.htmlに記載のロードマップの0.5倍のサイズとすること。
-->



# できること

本ページでは「smabo-brain-ros」のセットアップ手順について解説します。

<br>

具体的には、以下の内容を実施します。

- smabo-brain-rosのセットアップ

# 構成

今回は、下図のようになります。

<!-- 以下の、smabo_sysytem_architecture.drawio.svgの代わりに、sysmap.jsをもとに作成したアーキテクチャ図を配置する。-->
<!-- 以下例のように記述するので、ハイライトするノードと矢印、およびラベルに記述する内容を確認し、アーキテクチャ図を作成してください -->
<!-- 例）コンポーネント1 -[websocket]-> コンポーネント2：データ種類1, データ種類2 -->
<!-- 今回の、具体的な構成は以下になります。 -->
<!-- smabo-brain -[websocket]-> smabo-esp32 : 速度指令, サーボ制御 -->
<!-- smabo-esp32 -[websocket]-> smabo-brain : ホイール速度, LiDAR -->



# smabo-brain-rosとは

smabo-brain-rosはsmaboの中で

- smabo-brainの純ロジック（オドメトリ積分など）をROS 2ノードとして公開する

役割を担います。

<br>

ROS 2を導入することで、ナビゲーション（Nav2）や動作計画（MoveIt2）といった既存のROSエコシステムを活用できるようになります。

!!! note
    ROS 2（Humble以降）が必要です。また、smabo-brainがimport可能であること（`brain`パッケージ）が前提です。

## smabo-brain-rosのクローン

以下コマンドでsmabo-brain-rosリポジトリをクローンします。

```bash
# ホームディレクトリへ移動
cd ~ 
```

```bash
# smabo-brain-rosリポジトリのクローン
git clone https://github.com/smabo-smartphone-robot/smabo-brain-ros
```

## ビルド

付属のスクリプトで、ワークスペースの作成・リンク・ビルドを行います。

```bash
cd ~/smabo-brain-ros
```

```bash
./build.sh
```

# 動作手順

以下手順で、動作の確認を行います。

以下コマンドで、オドメトリノードを起動します。

```bash
cd ~/smabo-brain-ros
```

```bash
./run.sh
```

<br>

別ターミナルで`/odom`トピックが配信されていればOKです。

```bash
ros2 topic echo /odom
```

# 次回

次回は、以下ロードマップの

- [ナビゲーション](./nav.md)
- [動作計画](./plan.md)

について解説します。

<!--
htmlに変換する際は、以下のsvgファイルの代わりに、roadmap.htmlに記載してあるロードマップを添付すること。ただし、次回につながるノードをハイライトした状態にすること。また、roadmap.htmlに記載のロードマップの0.5倍のサイズとすること。
-->



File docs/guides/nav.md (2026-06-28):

<!--
以下は、md -> html 生成の際の指示（html生成時に直接出力する箇所ではない。以降、コメントアウトしてある箇所は、html生成時の注意事項が記載してあるものとする）

- markdownにて記載した文章は、誤字・脱字を除き、一切省略せずに、全く同じ文章でhtmlに反映すること（改行のタイミングなども含む）
    - 追記、修正した方がいい文章があった場合は、必ずユーザーに確認した上で、了承を得られた場合のみmarkdown, htmlともに修正すること
- 誤字、脱字があった場合は、markdown,html両方とも修正すること
- 表記揺れがあった場合は、どちらに統一するかユーザー側に確認したのちに、markdown, htmlともに、指定された表記に統一されるように修正すること
- 処理内容などに言及する部分に関しては、間違いがないか（コードが存在する場合は）コードの内容と照らし合わせて確認すること。その際、不整合があった場合は、ユーザー側に確認した上で了承が得られたら、markdown,htmlともに修正すること
- その他不正確な内容が含まれている場合は、ユーザー側に確認した上で了承が得られたら、markdown,htmlともに修正すること
-->

# 目次 <!-- omit in toc -->

- [ロードマップ](#ロードマップ)
- [できること](#できること)
- [構成](#構成)
- [ナビゲーションとは](#ナビゲーションとは)
- [動作手順](#動作手順)
- [次回](#次回)

# ロードマップ

本ページは、以下ロードマップ「ナビゲーション」のガイドページです。

また、本ページは「[エンコーダ付移動ロボット](./encmobile.md)」と「[brain-ros](./brainros.md)」のガイドを実施している前提で話を進めます。

<!--
htmlに変換する際は、以下のsvgファイルの代わりに、roadmap.htmlに記載してあるロードマップを添付すること。ただし、本ページのノードをハイライトした状態にすること。また、roadmap.htmlに記載のロードマップの0.5倍のサイズとすること。
-->



# できること

本ページでは「ナビゲーション」機能の実装について解説します。

<br>

具体的には、以下の内容を実施します。

- 目標地点を指定しての自律移動

# 構成

今回は、下図のようになります。

<!-- 以下の、smabo_sysytem_architecture.drawio.svgの代わりに、sysmap.jsをもとに作成したアーキテクチャ図を配置する。-->
<!-- 以下例のように記述するので、ハイライトするノードと矢印、およびラベルに記述する内容を確認し、アーキテクチャ図を作成してください -->
<!-- 例）コンポーネント1 -[websocket]-> コンポーネント2：データ種類1, データ種類2 -->
<!-- 今回の、具体的な構成は以下になります。 -->
<!-- smabo-brain -[websocket]-> smabo-esp32 : 速度指令 -->
<!-- smabo-esp32 -[websocket]-> smabo-brain : ホイール速度, LiDAR -->



# ナビゲーションとは

ナビゲーションは、エンコーダによるオドメトリ（自己位置）をもとに、

- 目標地点までの経路の生成
- 経路に沿った走行制御

を行う機能です。

<br>

smaboでは、smabo-brain-rosで公開される`/odom`をもとに、ROS 2のナビゲーションスタック（Nav2）を用いて実現します。

!!! note
    具体的な手順は oooo

# 動作手順

以下手順で、動作の確認を行います。

oooo

# 次回

本ページはロードマップ上の終着点のひとつです。

他の機能も実装する場合は、ロードマップから次のページへ進んでください。



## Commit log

2026-06-24 add smabo-esp32
    [esp32_battery_box.fzz]
2026-06-24 smabo-esp32: rephrase for better clarity
2026-06-27 fix composition
    [esp32_battery_box.fzz]
2026-06-27 add smabo-sensor smabo-face audio-process
2026-06-30 update startup
    [hand.fzz]
2026-07-03 Change navigation buttons to GitHub only.
2026-07-06 Fix header overlap on phone widths
    JP/EN switch and GitHub button overlapped the smabo logo below ~480px
    since the header nav had no mobile-specific sizing. Shrink logo, nav
    gaps, and button padding at that breakpoint.
2026-07-06 Replace roadmap section with a "Start building smabo" CTA button
    The interactive roadmap graph is dropped from the index pages per the
    revised index.md; two outline CTA buttons (hero + footer) linking to
    guides/smabo-brain.html take its place. Unused roadmap.js/sysmap.js/css
    references and the tooltip markup are removed from both index pages
    (the files themselves remain for the guide pages that still use them).
    The CTA button uses a new .btn--outline style matching the roadmap's old
    "Read Guide" pill, and scales gently with viewport width via clamp() so
    it doesn't look undersized on wide screens while staying comfortably
    sized on phones.
2026-07-06 Pin index page hero/media/CTA to a fixed size instead of scaling with viewport
    Hero image and feature videos are fixed at 600px from ~600px viewport width
    upward, only shrinking proportionally below that to fit phones. The CTA
    button drops its clamp()-based growth in favor of one fixed size, with a
    wrap/max-width safety net so it still can't overflow on very narrow screens.
2026-07-06 Exclude the CTA button from scroll-reveal so it's always visible
    The "Start building smabo" button matched the same selector as the fade-in
    content blocks, so it was hidden until scrolled into view. Always show it.
2026-07-07 Convert mobile.md to a full guide page (JP + EN), add tt_motor assembly viewer
    - guides/mobile.html and en/guides/mobile.html built from mobile.md: roadmap
    embed, custom sysmap data-flow diagram, parts table, printing photos,
    assembly viewer, wiring table/diagrams, operation instructions.
    - assembly_movie/smabo_tt_motor.html: new interactive assembly viewer
    continuing base_bread_board.html's 14-part sequence with the tt_motor/
    caster parts (a stray duplicate mesh from the source STEP file was
    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
2026-07-07 Fix table right-edge white gap; move SBC/raspi print+assembly into base guide
    - docs.css: drop display:block from .doc-content table — it broke the
    table's own column auto-layout, so short/narrow tables (e.g. smabo-app's
    single-row parts table) rendered their bordered box at full width while
    header/cell backgrounds only spanned the auto-sized columns, leaving a
    blank strip on the right. overflow-x:auto alone still handles scrolling
    for genuinely wide tables.
    - base.md/html (JP+EN): add "smabo-brainをSBCにセットアップした場合 >
    SBC=ラズパイ(4 or 5)の場合" under both Printing and Assembly, with the
    raspi_stand/stopper1/stopper2 prints and the smabo_raspi.html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
2026-07-07 Add brain->web websocket flow (image processing result) to mobile sysmap
    Matches the updated roadmap_popup.md/mobile.md source; the ws lane between
    smabo-brain and smabo-web already existed in sysmap.js's flow geometry.
2026-10-26 SEO: noindex (indexifembedded) assembly viewers and drop them from sitemap
2026-10-26 SEO: exclude assembly viewers from sitemap via front matter
2026-11-01 SEO: add the reading スマボ to the Japanese top page and site name data
2026-11-12 Move the site from Jekyll (docs/) to Astro Starlight (astro/)
    - Guides (ja/en), top pages and the design doc are now Starlight md in
    astro/src/content/docs; images, videos, wiring and assembly viewers in
    astro/public. Text unchanged.
    - Roadmap/system diagrams, startup popup and Mermaid run from public/js.
    - Unpublished drafts converted to Starlight format in astro/drafts.
    - Build checks internal links (starlight-links-validator); Partytown is
    ready for analytics scripts.
    - GitHub Actions builds astro/ and deploys to Pages.
    - docs/ removed; slides moved to slide/. .gitignore drops the old Jekyll
    entries and no longer ignores package-lock.json (needed by npm ci).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
2026-11-13 Update guides and design doc for the new smabo-web
    Templates/panels become tabs, smabo-web screenshots retaken, the design
    doc covers the settings relay and opt-in pairing, and mermaid diagrams
    are refitted so they are no longer clipped.
2026-11-13 Finish the robot arm guide
    Assembly photos (WebP), the controller video (mp4), the wiring diagram, the
    assembly viewer and an interactive joint-range viewer.
2026-11-13 Mark the robot arm ready and follow dark mode in roadmap popups
    Drop the sidebar's Coming soon badge and give the roadmap node a real popup.
    The popups (and the system diagram inside) now switch to dark colours.
2026-11-13 Compress large images and drop unused ones
    PNGs over 150 KB are reduced to 256 colours under the same names (images:
    11.4 MB -> 3.3 MB, fritzing wiring diagrams: 1.36 MB -> 0.48 MB). Three
    screenshots that no page uses are removed.
2026-11-13 Call the arm guide's roadmap node Robot Arm, not Hand

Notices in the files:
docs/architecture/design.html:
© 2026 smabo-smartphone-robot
